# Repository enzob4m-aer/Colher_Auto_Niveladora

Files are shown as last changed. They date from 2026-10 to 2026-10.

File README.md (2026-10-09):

## Colher_Auto_Niveladora
Protótipo de uma colher nivelada quando a mão se inclina, pensada para pessoas com dificuldade motora, feito com: Arduino, MPU6050, Servo MG995 e peças impressas em 3D

## Como funciona:
Um sensor de inclinação (MPU6050) preso no cabo mede o quanto a mão
inclinou. O Arduino calcula o giro contrário e o servo gira a colher,
que continua nivelada.

## O que funciona hoje:
- Estrutura mecânica projetada no Fusion 360 e impressa em 3D
- Controle do servo com movimento suave, comandado por potenciômetro
- Geração do sinal do servo sem biblioteca, para eliminar a tremedeira
  que a biblioteca padrão causava nesta placa

## O que faltou:
O sensor MPU6050 apresentou defeito, identificado com um teste pino a
pino (`ponta_de_prova`). O código de nivelamento (`colher_niveladora`)
está pronto e foi validado em simulação; o teste real será feito com
um sensor novo.

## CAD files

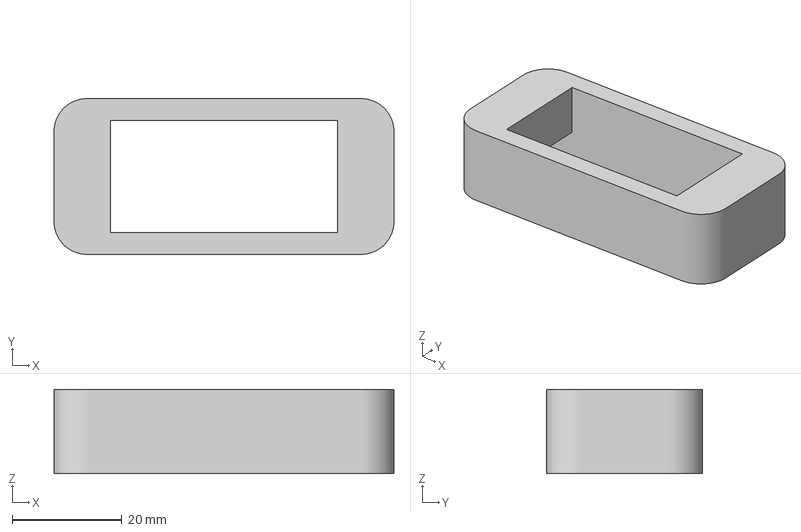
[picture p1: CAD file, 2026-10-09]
TAMPA.3mf
62.0 x 28.4 x 15.4 mm

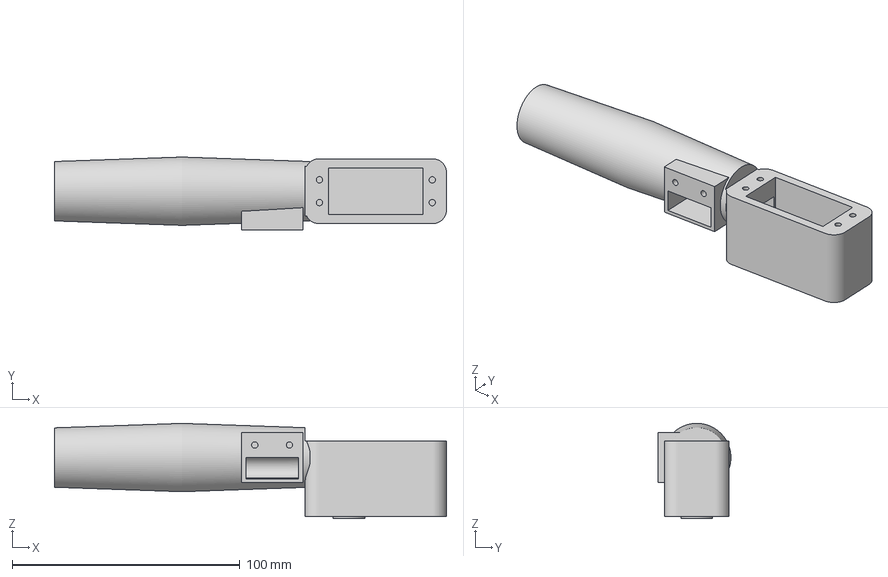
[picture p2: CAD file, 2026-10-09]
CABO.3mf
172.0 x 32.0 x 41.8 mm

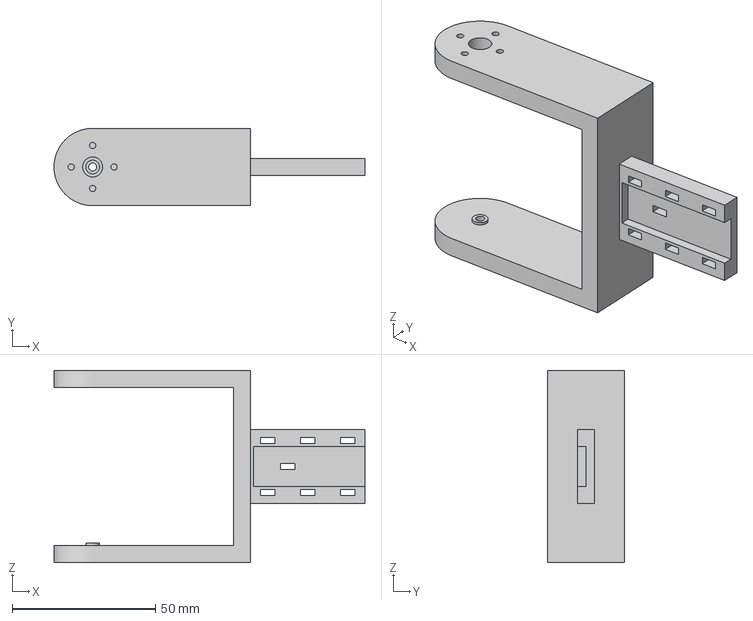
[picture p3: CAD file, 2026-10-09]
GARFO.3mf
108.6 x 27.0 x 67.2 mm

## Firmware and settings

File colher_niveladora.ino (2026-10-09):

//  COLHER NIVELADORA - (Arduino UNO Q)
//
//  O que faz, 100 vezes por segundo:
//   1) Le o MPU6050 (preso no CABO) e calcula a inclinacao do cabo.
//   2) Calcula quanto o servo precisa girar para a COLHER ficar
//      no angulo desejado (o "alvo"), mesmo com o cabo inclinado.
//   3) Move o servo de forma suave.
//
//  AO LIGAR: deixe a colher PARADA, apoiada na mesa, por uns 5 segundos.

#include <Arduino_RouterBridge.h>
#include <Wire.h>
#include <Servo.h>

// AJUSTES 
const int   SINAL         = 1;      // se a colher girar para o lado ERRADO, troque para -1
const int   US_CENTRO     = 1500;   
const float US_POR_GRAU   = 10.0;   

const bool  USAR_POTS     = true;   // false = ignora os potenciometros e usa os valores fixos abaixo
const float ALVO_FIXO     = 0.0;   
const float PASSO_FIXO    = 3.0;    

const int   PINO_SERVO     = 9;
const int   PINO_POT_ALVO  = A2;
const int   PINO_POT_SUAVE = A3;
const float ALVO_MAX      = 20.0;   
const float PASSO_MINIMO  = 1.0;    
const float PASSO_MAXIMO  = 5.0;    

const float LIMITE        = 45.0;   
const float ZONA_MORTA    = .0;    
const float ANG_SEGURANCA = 70.0;   
const float ALFA          = 0.98;   
const unsigned long TEMPO_SEM_SENSOR = 300;   

const uint8_t ENDERECO_MPU = 0x68;

Servo servo;
TwoWire *barramento = &Wire;        

float biasGy = 0;                  
float angulo = 0;                  
float alvo = ALVO_FIXO;            
float passo = PASSO_FIXO;         
float comando = 0;               
float comandoEnviado = 0;        
bool sensorOk = false;
unsigned long tAnterior = 0;     
unsigned long tUltimaBoa = 0;     
unsigned long tTela = 0;           
unsigned long tPots = 0;        

// ---------------- SERVO ----------------
void moverServo(float graus) {
  int us = US_CENTRO + (int)(graus * US_POR_GRAU);
  us = constrain(us, 1000, 2000);   // nunca sai da faixa segura do MG995
  servo.writeMicroseconds(us);
  comandoEnviado = graus;
}

// ---------------- SENSOR ----------------
void escrever(int reg, int valor) {
  barramento->beginTransmission(ENDERECO_MPU);
  barramento->write(reg);
  barramento->write(valor);
  barramento->endTransmission();
}

bool lerSensor(float &ax, float &az, float &gy) {
  barramento->beginTransmission(ENDERECO_MPU);
  barramento->write(0x3B);                           
  if (barramento->endTransmission(false) != 0) return false;   
  barramento->requestFrom(ENDERECO_MPU, 14);
  if (barramento->available() < 14) {
    while (barramento->available()) barramento->read();
    return false;
  }
  int16_t bruto[7];
  for (int i = 0; i < 7; i++) {
    int alto  = barramento->read();
    int baixo = barramento->read();
    bruto[i] = (int16_t)((alto << 8) | baixo);
  }
  if (bruto[0] == 0 && bruto[1] == 0 && bruto[2] == 0) return false;
  ax = bruto[0] / 16384.0;
  az = bruto[2] / 16384.0;
  gy = bruto[5] / 131.0;
  return true;
}

bool responde(TwoWire &pinos) {
  pinos.begin();
  pinos.setClock(100000);
  pinos.beginTransmission(ENDERECO_MPU);
  pinos.write(0x75);
  return pinos.endTransmission() == 0;
}

bool iniciarSensor() {
  if (responde(Wire)) {
    barramento = &Wire;
    Monitor.println("Sensor encontrado nos pinos SDA/SCL do topo.");
  } else if (responde(Wire2)) {
    barramento = &Wire2;
    Monitor.println("Sensor encontrado nos pinos A4/A5.");
  } else {
    return false;
  }

  escrever(0x6B, 0);                
  escrever(0x1A, 3);                
  escrever(0x1B, 0);                
  escrever(0x1C, 0);                
  delay(100);                       

  Monitor.println("Calibrando: deixe a colher PARADA...");
  float ax, az, gy, soma = 0;
  int boas = 0;
  for (int i = 0; i < 200; i++) {
    if (lerSensor(ax, az, gy)) { soma += gy; boas++; }
    delay(5);
  }
  if (boas < 100) return false;     
  biasGy = soma / boas;

  if (!lerSensor(ax, az, gy)) return false;
  angulo = atan2(-ax, az) * 57.2958;   
  comando = comandoEnviado;         
  tAnterior = micros();
  tUltimaBoa = millis();
  return true;
}

// POTENCIOMETROS 
void lerPotenciometros(bool suave) {
  if (!USAR_POTS) return;
  float peso = suave ? 0.2 : 1.0;

  int leitura = analogRead(PINO_POT_ALVO);            
  if (leitura >= 0) {
    leitura = constrain(leitura, 0, 1023);
    float novo = (leitura / 1023.0 * 2.0 - 1.0) * ALVO_MAX;   
    if (fabs(novo) < 1.5) novo = 0;                   
    alvo = (1 - peso) * alvo + peso * novo;
  }

  leitura = analogRead(PINO_POT_SUAVE);
  if (leitura >= 0) {
    leitura = constrain(leitura, 0, 1023);
    float novo = PASSO_MINIMO + leitura / 1023.0 * (PASSO_MAXIMO - PASSO_MINIMO);
    passo = (1 - peso) * passo + peso * novo;
  }
}

// INICIO 
void setup() {
  servo.attach(PINO_SERVO);
  moverServo(0);                    

  Bridge.begin();                   
  Monitor.begin();
  delay(3000);

  lerPotenciometros(false);
  sensorOk = iniciarSensor();
  if (sensorOk) Monitor.println("Pronto.");
}

// CICLO 
void loop() {
  if (!sensorOk) {
    moverServo(0);
    comando = 0;
    Monitor.println("ERRO: MPU6050 nao respondeu. Colher no centro. Tentando de novo...");
    delay(2000);
    sensorOk = iniciarSensor();
    if (sensorOk) Monitor.println("Pronto.");
    return;
  }

  float ax, az, gy;
  if (!lerSensor(ax, az, gy)) {
    if (millis() - tUltimaBoa > TEMPO_SEM_SENSOR) sensorOk = false;
    tAnterior = micros();
    delay(10);
    return;
  }
  tUltimaBoa = millis();

  unsigned long agora = micros();
  float dt = (agora - tAnterior) / 1000000.0;        
  tAnterior = agora;
  float anguloAcc = atan2(-ax, az) * 57.2958;
  if (dt > 0.2) {
    angulo = anguloAcc;             
  } else {
    angulo = ALFA * (angulo + (gy - biasGy) * dt) + (1 - ALFA) * anguloAcc;
  }

  if (millis() - tPots >= 50) {
    tPots = millis();
    lerPotenciometros(true);
  }

  float desejado = SINAL * (alvo - angulo);
  desejado = constrain(desejado, -LIMITE, LIMITE);
  if (fabs(angulo) > ANG_SEGURANCA) desejado = 0;    

  comando += constrain(desejado - comando, -passo, passo);

  if (fabs(comando - comandoEnviado) >= ZONA_MORTA) {
    moverServo(comando);
  }

  if (millis() - tTela >= 100) {
    tTela = millis();
    Monitor.print("angulo_cabo:");
    Monitor.print(angulo, 1);
    Monitor.print(",compensacao:");
    Monitor.print(comandoEnviado, 1);
    Monitor.print(",alvo:");
    Monitor.println(alvo, 1);
  }
  delay(10);                        
}

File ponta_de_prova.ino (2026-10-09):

// =============================================================
//  PONTA DE PROVA (Arduino UNO Q)
//
//  Transforma o pino A4 num "testador": um fio sai do A4 e a outra
//  ponta voce encosta no ponto que quer medir. A tela mostra, 2 vezes
//  por segundo, o que ha naquele ponto:
//     3,3 V  = ligado ao positivo 
//     0 V    = ligado ao GND 
//     SOLTO  = nao esta encostando em nada
//
//  CUIDADO: nunca encoste a ponta no trilho de 5V da fonte
// =============================================================
#include <Arduino_RouterBridge.h>

const int PINO_PROVA = A4;

// 0 = 0 V | 1 = solto | 2 = 3,3 V
int medir() {
  pinMode(PINO_PROVA, INPUT_PULLUP);      // puxa de leve para cima e olha
  delay(5);
  bool altoPuxandoParaCima = (digitalRead(PINO_PROVA) == HIGH);
  pinMode(PINO_PROVA, INPUT_PULLDOWN);    // puxa de leve para baixo e olha
  delay(5);
  bool altoPuxandoParaBaixo = (digitalRead(PINO_PROVA) == HIGH);
  if (!altoPuxandoParaCima) return 0;     // nem puxando para cima subiu: esta em 0 V
  if (!altoPuxandoParaBaixo) return 1;    // vai para onde eu puxo: esta solto
  return 2;                               // nem puxando para baixo desceu: esta em 3,3 V
}

void setup() {
  Bridge.begin();
  Monitor.begin();
  delay(3000);
  Monitor.println("Ponta de prova no pino A4. Encoste a outra ponta do fio no ponto a medir.");
}

void loop() {
  int resultado = medir();
  if (resultado == 0) Monitor.println("0 V");
  if (resultado == 1) Monitor.println("SOLTO");
  if (resultado == 2) Monitor.println("3,3 V");
  delay(500);
}
